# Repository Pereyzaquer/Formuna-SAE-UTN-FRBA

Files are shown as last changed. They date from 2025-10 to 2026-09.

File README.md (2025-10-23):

# Fórmula SAE - UTN-FRBA

<p>Este repositorio está destinado al equipo de <strong>Fórmula SAE UTN-FRBA</strong>.<br>
Su objetivo es centralizar y compartir los <strong>esquemáticos</strong>, <strong>código</strong> y <strong>documentación técnica</strong> correspondientes a las distintas áreas del proyecto.</p>

<p>Para consultas, dudas o reportes de problemas, comuníquese con el responsable del área correspondiente.</p>

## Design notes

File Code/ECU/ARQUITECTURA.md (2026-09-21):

# Arquitectura del firmware

Vista de alto nivel de como esta armado el codigo de la ECU y de los
nodos sensores.

- Como correr la prueba: [PRUEBA.txt](../PRUEBA.txt)
- Decisiones tomadas y pendientes: [TODO.txt](TODO.txt)
- Mapa de identificadores CAN: [include/can_ids.h](include/can_ids.h)

---

## 1. Que hay conectado

Cada sensor vive en su propia placa y publica por CAN. La ECU no lee
ningun sensor de forma directa: solo escucha el bus.

```mermaid
flowchart LR
    N1["Nodo temperatura<br/>NodeMCU + DHT11<br/>ID 0x480 - 1 Hz"]
    N2["Nodo rueda delantera<br/>Nano + LJ12A3 inductivo<br/>ID 0x200 - 20 Hz"]
    N3["Nodo rueda trasera<br/>ESP32-C3 + infrarrojo LM393<br/>ID 0x201 - 20 Hz"]
    BUS{{"Bus CAN 500 kbps"}}
    ECU["ECU<br/>ESP32-S3"]
    PC["Navegador<br/>celular o notebook"]

    N1 --> BUS
    N2 --> BUS
    N3 --> BUS
    BUS <--> ECU
    ECU -. "heartbeat 0x100 - 100 Hz" .-> BUS
    ECU ---|"WiFi propio<br/>192.168.4.1"| PC
```

Los dos sensores de rueda son distintos por dentro y comparten codigo:
los dos bajan su salida a cero cuando pasa algo por delante. Con dos
ruedas reportando, la ECU ya puede calcular la velocidad del auto y
descartar la que se aparta.

---

## 2. Como conectar todo

Armado de la prueba de banco: **una ECU y tres nodos, los cuatro por
modulo MCP2515.** Hay cuatro modulos HW-184, uno por placa.

### Lista de materiales

| Cantidad | Que | Para que |
| --- | --- | --- |
| 1 | ESP32-S3 (YD-ESP32-S3) | ECU |
| 1 | ESP32-C3 Super Mini | Nodo infrarrojo, rueda trasera |
| 1 | NodeMCU V3 LoLin (ESP8266) | Nodo DHT11 |
| 1 | Arduino Nano | Nodo inductivo, rueda delantera |
| 4 | Modulo HW-184 (MCP2515 + TJA1050) | Uno por placa |
| 2 | Conversor de nivel 5 V / 3.3 V, 4 canales | ECU y ESP32-C3 |
| 1 | Resistencia de 1 kohm | Divisor del NodeMCU, recomendado |
| 1 | Resistencia de 2 kohm (o 2.2) | Divisor del NodeMCU, recomendado |
| 1 | Modulo infrarrojo de obstaculos LM393 | Sensor de rueda trasera |
| 1 | DHT11 | Sensor de temperatura |
| 1 | LJ12A3-4-Z/BX | Sensor de rueda delantera |
| 2 | Algo que gire con una lengüeta | Uno de metal para el inductivo, uno de lo que sea para el infrarrojo |
| 4 | Cable USB | Alimentacion y programacion |

**Por que hay dos conversores y un divisor.** El HW-184 es de 5 V.
El Nano tambien: va directo. El ESP32-S3, el ESP32-C3 y el NodeMCU son
de 3.3 V y no toleran 5 V en sus entradas. Hay dos conversores: van a
los dos ESP32, con las cuatro lineas del SPI cada uno. Al NodeMCU no le
alcanza conversor, y se resuelve con dos resistencias en la unica linea
que vuelve del modulo con 5 V, la SO.

### Vista general

```mermaid
flowchart LR
    subgraph ecu["ECU - ESP32-S3"]
        S3["SPI GPIO 10-13"]
    end
    subgraph n1["Nodo rueda trasera - ESP32-C3"]
        C3["SPI GPIO 4-7<br/>GPIO 8 pulsos"]
    end
    subgraph n2["Nodo temperatura - NodeMCU"]
        NM["SPI D5 D6 D7, CS D2<br/>D1 datos"]
    end
    subgraph n3["Nodo rueda delantera - Nano"]
        NANO["SPI D10-D13<br/>D3 pulsos"]
    end

    SH1["Conversor<br/>de nivel"]
    SH2["Conversor<br/>de nivel"]
    DIV["Divisor 1k / 2k<br/>solo en SO"]
    M1["HW-184"]
    M2["HW-184"]
    M3["HW-184"]
    M4["HW-184"]
    BUS{{"CAN_H y CAN_L<br/>120 ohm solo en las dos puntas"}}

    S3 --- SH1 --- M1 --- BUS
    C3 --- SH2 --- M2 --- BUS
    NM --- DIV --- M3 --- BUS
    NANO --- M4 --- BUS

    IR["Infrarrojo LM393"] --- C3
    DHT["DHT11"] --- NM
    LJ["LJ12A3 inductivo"] --- NANO
```

Todas las masas van unidas: las cuatro placas, los cuatro modulos y
los conversores. Es lo primero que hay que cablear y lo primero que hay
que revisar si algo no anda.

### El bus CAN

| Conexion | Detalle |
| --- | --- |
| CAN_H | Un cable que pasa por la bornera H de los cuatro HW-184 |
| CAN_L | Idem con la L. Conviene trenzar los dos |
| Orden | Lineal: ECU - C3 - NodeMCU - Nano, o el que convenga, pero en fila, no en estrella |
| 120 ohm | **Solo en los dos modulos de las puntas.** Los dos del medio tienen que quedar sin terminador |
| Velocidad | 500 kbps, ya fijada en el codigo |

**Los terminadores.** Cada HW-184 trae su resistencia de 120 ohm con
un jumper marcado J1. Con cuatro modulos, dos son extremos y dos estan
en el medio: **quitar el jumper J1 en los dos del medio.** Si en vez de
jumper es un puente soldado, cortarlo. Con cuatro terminadores el bus
queda cargado de mas y aparecen errores intermitentes que enloquecen.

**El cristal del MCP2515.** Cada HW-184 tiene una lata metalica con un
numero: 8.000 o 16.000. El codigo asume **8 MHz** en las cuatro placas.
Si alguno dice 16, hay que cambiar `MCP2515_CRYSTAL` en el
`can_mcp2515.cpp` que corresponda. Si no coincide, ese nodo queda a otra
velocidad y no se entiende con nadie, sin ningun mensaje de error.

### Nodo rueda trasera: ESP32-C3 + conversor + HW-184 + infrarrojo

Alimentacion:

| De | A |
| --- | --- |
| C3 3.3V | Conversor lado LV, y VCC del modulo infrarrojo |
| C3 5V | Conversor lado HV, y VCC del HW-184 |
| C3 GND | Conversor GND, HW-184 GND, infrarrojo GND, masa comun |

SPI, las cuatro lineas por el conversor:

| ESP32-C3 | Conversor | HW-184 |
| --- | --- | --- |
| GPIO 4 | LV1 - HV1 | SCK |
| GPIO 6 | LV2 - HV2 | SI |
| GPIO 5 | LV3 - HV3 | SO |
| GPIO 7 | LV4 - HV4 | CS |
| — | — | INT: sin conectar |

Sensor infrarrojo LM393:

| Modulo | C3 |
| --- | --- |
| VCC | 3.3V |
| GND | GND |
| D0 | GPIO 8, directo. El modulo ya trae pull-up |

El modulo tiene un preset. Girarlo hasta que su led encienda con la
lengüeta delante y se apague sin ella, a la distancia a la que va a
trabajar. Si queda muy sensible dispara solo y las RPM salen infladas.

### Nodo temperatura: NodeMCU + divisor + HW-184 + DHT11

Alimentacion:

| De | A |
| --- | --- |
| NodeMCU VU (5 V del USB) | VCC del HW-184 |
| NodeMCU 3V3 | VCC del DHT11 |
| NodeMCU GND | HW-184 GND, DHT11 GND, masa comun |

SPI. Tres lineas van directo del NodeMCU al modulo con 3.3 V, que el
MCP2515 acepta. La que vuelve, SO, sale con 5 V y conviene bajarla con
el divisor. Sin el divisor anda: el ESP8266 aguanta 5 V en la practica,
aunque la hoja de datos no lo garantiza. Para el banco es aceptable
conectar SO directo a D6; para algo que dure, poner las dos
resistencias.

| NodeMCU | HW-184 |
| --- | --- |
| D5 | SCK, directo |
| D7 | SI, directo |
| D6 | SO, **por el divisor** |
| D2 | CS, directo |
| — | INT: sin conectar |

El divisor: 1 kohm entre SO del HW-184 y D6, y 2 kohm entre D6 y GND.
Los 5 V del modulo llegan a D6 como 3.3 V.

**No usar D8 como CS**: es un pin de arranque del ESP8266 y el modulo lo
puede dejar en un nivel que impide que la placa bootee. D2 no tiene ese
problema.

DHT11:

| DHT11 | NodeMCU |
| --- | --- |
| DATA | D1, directo. La libreria activa la pull-up interna del micro |
| VCC | 3V3 |
| GND | GND |

### Nodo rueda delantera: Nano + HW-184 + inductivo

Todo a 5 V, sin conversor ni divisor.

| Nano | HW-184 |
| --- | --- |
| D13 | SCK |
| D11 | SI |
| D12 | SO |
| D10 | CS |
| 5V | VCC |
| GND | GND |
| — | INT: sin conectar |

Sensor inductivo LJ12A3-4-Z/BX, alimentado con los 5 V del Nano:

| Cable | Nano |
| --- | --- |
| Marron | 5V |
| Azul | GND |
| Negro | D3, directo. El codigo activa la pull-up interna del Nano |

El sensor tiene un led que enciende al detectar metal. Sirve para
ajustar la distancia a la lengüeta, unos 2 a 3 mm, antes de conectar
nada. Alimentado con 5 V su salida no puede pasar de 5 V, asi que va
directo al Nano sin mas verificacion.

Si la lectura de RPM sale con ruido o saltos raros, agregar 4.7 kohm
entre D3 y 5V: es una pull-up mas fuerte que la interna del micro.

### ECU: ESP32-S3 + conversor + HW-184

Alimentacion:

| De | A |
| --- | --- |
| ESP32 3.3V | Conversor lado LV |
| ESP32 5V | Conversor lado HV, y VCC del HW-184 |
| ESP32 GND | Conversor GND, HW-184 GND, masa comun |

SPI, las cuatro lineas por el conversor:

| ESP32-S3 | Conversor | HW-184 |
| --- | --- | --- |
| GPIO 12 | LV1 - HV1 | SCK |
| GPIO 11 | LV2 - HV2 | SI |
| GPIO 13 | LV3 - HV3 | SO |
| GPIO 10 | LV4 - HV4 | CS |
| — | — | INT: sin conectar |

Opcional: GPIO 6 a un boton de arranque, el otro extremo a GND. La
pagina web tiene el suyo.

### Orden de armado

1. Masa comun entre todo.
2. Bus: CAN_H y CAN_L en fila por los cuatro HW-184. Quitar J1 en los
   dos del medio.
3. Cada placa con su HW-184, segun las tablas: conversor en los dos
   ESP32, divisor en el NodeMCU, directo en el Nano.
4. Los tres sensores.
5. Grabar. Desde `Code/ECU`: `pio run -t upload`. Desde
   `Code/SensorNode`: `pio run -e rueda_c3 -t upload`,
   `-e temperatura_nodemcu`, `-e rueda_nano`. Antes de cada una,
   `pio device list` para confirmar que placa esta enchufada.
6. Encender todo, entrar a `http://192.168.4.1/` y mirar "Nodos
   presentes" y "Bus caido". Tienen que ser 3 y un contador quieto.
   Si es asi, el bus esta bien y el resto es cuestion de sensores.

---

## 3. Maquina de estados del vehiculo

Un solo lugar del programa decide en que estado esta el auto:
[state.cpp](src/state.cpp).

```mermaid
stateDiagram-v2
    [*] --> BOOT

    BOOT --> CONFIG : nodos de seguridad OK, tras 2 s de escucha
    BOOT --> FAULT : falla de nodo de seguridad
    CONFIG --> CAR_READY : nodos presentes configurados
    CAR_READY --> CAR_ON : secuencia RTD completa
    CAR_ON --> CAR_READY : duracion cumplida, o apagado pedido

    CONFIG --> FAULT : error CRITICAL
    CAR_READY --> FAULT : error CRITICAL
    CAR_ON --> FAULT : error CRITICAL
    FAULT --> BOOT : la causa de la falla desaparecio

    note left of CAR_ON
        Perder nodos o ruedas es WARNING:
        no cambia el estado ni corta la grabacion.
    end note

    note right of FAULT
        Enclavado: se sale reiniciando el micro,
        o solo, si la causa desaparece: vuelve
        a BOOT y termina esperando el boton RTD.
    end note
```

El led RGB de debug muestra el estado: BOOT azul, CONFIG amarillo,
CAR_READY verde fijo, CAR_ON verde pulsante, FAULT rojo.

CONFIG dura unos 10 ms mientras no exista el mensaje de configuracion
de nodos, asi que en el led practicamente no se ve.

**Que pasa si un nodo se pierde.** Un corte de comunicacion no es una
falla del auto: no cambia el estado ni corta una grabacion en curso.
La ECU trabaja con los nodos que aparecieron en los 2 s de escucha, no
con la lista completa del auto: los que nunca estuvieron no cuentan.
Si uno de los que estaban deja de emitir mas de 3 s, queda un WARNING
(codigo 0x0002) en el monitor, y si se pierden todas las ruedas a la
vez el codigo es 0x0003 (se detecta en medio segundo, porque el piloto
se queda sin velocidad). Cuando todo vuelve, el aviso se borra solo y
la grabacion, si habia una, siguio como si nada. Lo definí así para el
banco; queda pendiente validar en el definitivo.

**Como se sale de FAULT.** FAULT queda para fallas de seguridad reales
(nodos de categoria B), que hoy no estan implementadas. Se sale
reiniciando el micro, o solo si la causa desaparece: la ECU se rearma
y vuelve a BOOT, con su ventana de descubrimiento, hasta quedar en
CAR_READY esperando el boton.

**Duracion de la ejecucion.** 90 s por defecto, definidos para el
banco. Se cambia desde la pagina antes de arrancar (campo "Duracion",
hasta 180 s); viaja con la orden de arranque.

**Contador de caidas.** Cada vez que un nodo se calla suma uno a su
contador. Los tres contadores se ven en el monitor y van al CSV como
canales (`caidas_rueda_delantera`, `caidas_rueda_trasera`,
`caidas_temperatura`): con el valor al arrancar la ejecucion y un
escalon por cada corte, para que en el grafico se vea cuando paso.

---

## 4. Como esta dividido el codigo de la ECU

Tres tasks. El nucleo 1 corre lo que tiene que ser predecible, y el 0
queda para la radio, que es donde el stack de WiFi ya corre lo suyo.

Las tasks no comparten variables sueltas: se hablan por colas.

```mermaid
flowchart LR
    subgraph nucleo1["Nucleo 1 - tiempo real"]
        direction TB
        taskCan["taskCan - prioridad 4<br/>can.cpp"]
        taskState["taskState - prioridad 3<br/>state.cpp"]
    end

    subgraph nucleo0["Nucleo 0 - radio"]
        taskWifi["taskWifi - prioridad 1<br/>wifi.cpp"]
    end

    taskState -- "queueWifi<br/>encender / apagar" --> taskWifi
    taskWifi -- "queueEvents<br/>arrancar / detener" --> taskState
```

Los demas archivos no tienen task propia: son modulos que las tasks
llaman.

| Archivo | Que hace | Quien lo usa |
| --- | --- | --- |
| `state.cpp` | Maquina de estados | taskState |
| `can.cpp` | Bus CAN: despacho, handlers y heartbeat | taskCan |
| `can_mcp2515.cpp` | Hardware del bus: modulo MCP2515 por SPI (banco) | can.cpp |
| `can_twai.cpp` | Hardware del bus: CAN interno del ESP32 (auto) | can.cpp |
| `wifi.cpp` | Punto de acceso y actualizacion OTA | taskWifi |
| `sensors.cpp` | Que nodos estan presentes | taskCan, taskState |
| `logger.cpp` | Guarda las muestras de la ejecucion | taskCan, webmonitor |
| `speed.cpp` | Velocidad del auto a partir de las ruedas | taskCan, taskState |
| `errors.cpp` | Registra y latchea las fallas | las tres tasks |
| `indicators.cpp` | Led RGB de debug | taskState |
| `webmonitor.cpp` | Pagina, JSON y CSV | taskWifi |

El bus CAN tiene mas prioridad que la maquina de estados a proposito:
no puede perder tramas esperando a que los estados terminen su vuelta.

---

## 5. Que pasa durante una ejecucion

```mermaid
sequenceDiagram
    participant Nodo as Nodo C3
    participant Can as taskCan
    participant Log as logger
    participant Est as taskState
    participant Web as webmonitor
    participant Nav as Navegador

    Note over Nodo,Can: El nodo emite solo, sin que nadie le pregunte

    Nodo->>Can: trama CAN
    Can->>Can: marca el nodo como presente
    Can->>Log: valor convertido a unidad real
    Note over Log: fuera de la ejecucion solo<br/>actualiza el valor en vivo

    Nav->>Web: POST /api/rtd
    Web->>Est: evento por queueEvents
    Est->>Log: loggerStart

    loop 90 segundos
        Nodo->>Can: trama CAN
        Can->>Log: se guarda la muestra
    end

    Est->>Log: la ejecucion termina sola
    Nav->>Web: GET /registro.csv
    Web->>Log: lee las muestras
    Web-->>Nav: CSV con una columna por canal
```

El nodo nunca espera una orden: arranca midiendo y emitiendo. Eso es lo
que permite que la ECU lo descubra con solo escuchar, y que un nodo
ausente no trabe nada.

---

## 6. Como se agrega un sensor nuevo

Del lado del nodo, un sensor son cuatro funciones declaradas en
[SensorNode.h](../SensorNode/include/SensorNode.h). `main.cpp` no sabe que
sensor tiene conectado: se lo pregunta a esa interfaz.

```mermaid
flowchart LR
    main["main.cpp<br/>no sabe que sensor hay"]
    api["Interfaz del sensor"]
    s1["sensor_temperature.cpp"]
    s2["sensor_wheel_speed.cpp"]
    s3["sensor_nuevo.cpp"]

    main --> api
    api --> s1
    api --> s2
    api -.-> s3

    s1 -.-> nota["sensorInitialize<br/>sensorGetCanIdentifier<br/>sensorGetPeriodMilliseconds<br/>sensorBuildFrame"]
```

Los pasos:

1. Copiar uno de los `sensor_*.cpp` e implementar las cuatro funciones.
2. Definir el identificador y el layout de su trama en `can_ids.h`:
   unidad, escala, rango y endianness. Si emisor y receptor no coinciden
   en los cuatro, el dato no falla, miente en silencio.
3. Agregar un entorno en el `platformio.ini` del nodo. El archivo del
   sensor se elige con `build_src_filter`, asi que no hace falta ningun
   `#ifdef`.
4. Del lado de la ECU, sumar el handler en `can.cpp` y el canal en
   `LogChannel`.

No hay que tocar `main.cpp` ni `can.cpp` del nodo.

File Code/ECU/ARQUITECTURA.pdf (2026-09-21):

# Arquitectura del firmware

Vista de alto nivel de como esta armado el codigo de la ECU y de los nodos sensores.

Como correr la prueba: PRUEBA.txt
Decisiones tomadas y pendientes: TODO.txt
Mapa de identificadores CAN: include/can_ids.h

## 1. Que hay conectado

Cada sensor vive en su propia placa y publica por CAN. La ECU no lee ningun sensor de forma directa: solo escucha el bus.

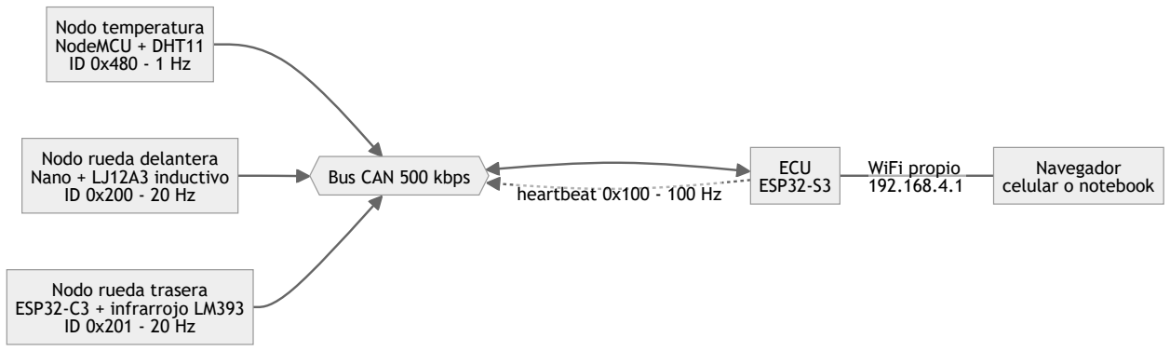
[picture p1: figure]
heartbeat 0x100 - 100 Hz; WiFi propio 192.168.4.1; Nodo temperatura NodeMCU + DHT11 ID 0x480 - 1 Hz; Nodo rueda delantera Nano + LJ12A3 inductivo ID 0x200 - 20 Hz; Nodo rueda trasera ESP32-C3 + infrarrojo LM393 ID 0x201 - 20 Hz; Bus CAN 500 kbps; ECU ESP32-S3; Navegador celular o notebook

Los dos sensores de rueda son distintos por dentro y comparten codigo: los dos bajan su salida a cero cuando pasa algo por delante. Con dos ruedas reportando, la ECU ya puede calcular la velocidad del auto y descartar la que se aparta.

## 2. Como conectar todo

Armado de la prueba de banco: una ECU y tres nodos, los cuatro por modulo MCP2515. Hay cuatro modulos HW-184, uno por placa.

Lista de materiales

Cantidad | Que | Para que
1 | ESP32-S3 (YD-ESP32-S3) | ECU
1 | ESP32-C3 Super Mini | Nodo infrarrojo, rueda trasera
1 | NodeMCU V3 LoLin (ESP8266) | Nodo DHT11
1 | Arduino Nano | Nodo inductivo, rueda delantera

Cantidad | Que | Para que
4 | Modulo HW-184 (MCP2515 + TJA1050) | Uno por placa
2 | Conversor de nivel 5 V / 3.3 V, 4 canales | ECU y ESP32-C3
1 | Resistencia de 1 kohm | Divisor del NodeMCU, recomendado
1 | Resistencia de 2 kohm (o 2.2) | Divisor del NodeMCU, recomendado
1 | Modulo infrarrojo de obstaculos LM393 | Sensor de rueda trasera
1 | DHT11 | Sensor de temperatura
1 | LJ12A3-4-Z/BX | Sensor de rueda delantera
2 | Algo que gire con una lengüeta | Uno de metal para el inductivo, uno de lo que sea para el infrarrojo
4 | Cable USB | Alimentacion y programacion

Por que hay dos conversores y un divisor. El HW-184 es de 5 V. El Nano tambien: va directo. El ESP32-S3, el ESP32-C3 y el NodeMCU son de 3.3 V y no toleran 5 V en sus entradas. Hay dos conversores: van a los dos ESP32, con las cuatro lineas del SPI cada uno. Al NodeMCU no le alcanza conversor, y se resuelve con dos resistencias en la unica linea que vuelve del modulo con 5 V, la SO.

Vista general

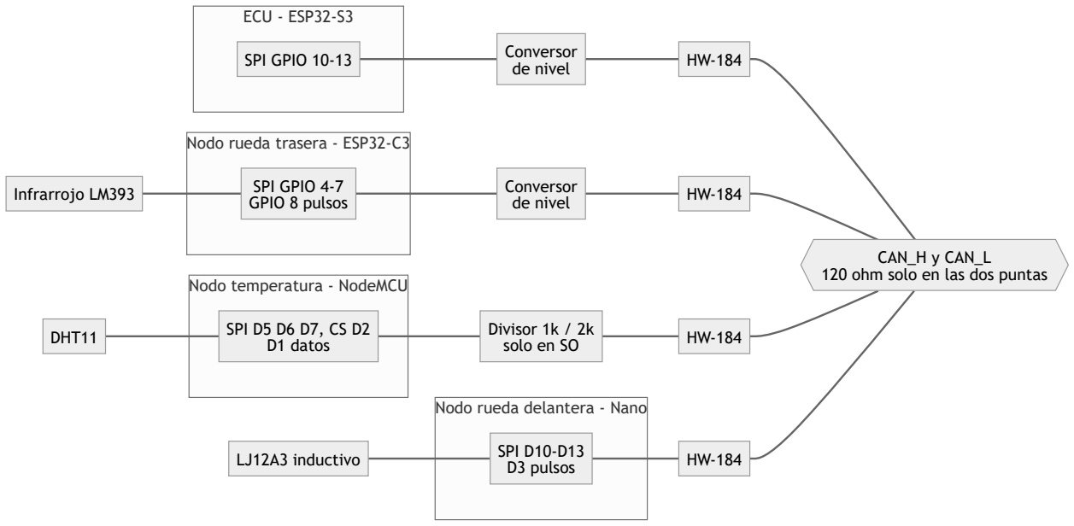
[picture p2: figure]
Nodo rueda delantera - Nano; Nodo temperatura - NodeMCU; Nodo rueda trasera - ESP32-C3; ECU - ESP32-S3; SPI D10-D13 D3 pulsos; SPI D5 D6 D7, CS D2 D1 datos; SPI GPIO 4-7 GPIO 8 pulsos; SPI GPIO 10-13; Conversor de nivel; Divisor 1k / 2k solo en SO; CAN_H y CAN_L 120 ohm solo en las dos puntas; Infrarrojo LM393; DHT11; LJ12A3 inductivo

Todas las masas van unidas: las cuatro placas, los cuatro modulos y los conversores. Es lo primero que hay que cablear y lo primero que hay que revisar si algo no anda.

El bus CAN

Conexion | Detalle
CAN_H | Un cable que pasa por la bornera H de los cuatro HW-184
CAN_L | Idem con la L. Conviene trenzar los dos
Orden | Lineal: ECU - C3 - NodeMCU - Nano, o el que convenga, pero en fila, no en estrella
120 ohm | Solo en los dos modulos de las puntas. Los dos del medio tienen que quedar sin terminador
Velocidad | 500 kbps, ya fijada en el codigo

Los terminadores. Cada HW-184 trae su resistencia de 120 ohm con un jumper marcado J1. Con cuatro modulos, dos son extremos y dos estan en el medio: quitar el jumper J1 en los dos del medio. Si en vez de jumper es un puente soldado, cortarlo. Con cuatro terminadores el bus queda cargado de mas y aparecen errores intermitentes que enloquecen.

El cristal del MCP2515. Cada HW-184 tiene una lata metalica con un numero: 8.000 o 16.000. El codigo asume 8 MHz en las cuatro placas. Si alguno dice 16, hay que cambiar MCP2515_CRYSTAL en el can_mcp2515.cpp que corresponda. Si no coincide, ese nodo queda a otra velocidad y no se entiende con nadie, sin ningun mensaje de error.

Nodo rueda trasera: ESP32-C3 + conversor + HW-184 + infrarrojo

Alimentacion:

De | A
C3 3.3V | Conversor lado LV, y VCC del modulo infrarrojo
C3 5V | Conversor lado HV, y VCC del HW-184
C3 GND | Conversor GND, HW-184 GND, infrarrojo GND, masa comun

SPI, las cuatro lineas por el conversor:

ESP32-C3 | Conversor | HW-184
GPIO 4 | LV1 - HV1 | SCK
GPIO 6 | LV2 - HV2 | SI
GPIO 5 | LV3 - HV3 | SO
GPIO 7 | LV4 - HV4 | CS
— | — | INT: sin conectar

Sensor infrarrojo LM393:

Modulo | C3
VCC | 3.3V
GND | GND
D0 | GPIO 8, directo. El modulo ya trae pull-up

El modulo tiene un preset. Girarlo hasta que su led encienda con la lengüeta delante y se apague sin ella, a la distancia a la que va a trabajar. Si queda muy sensible dispara solo y las RPM salen infladas.

Nodo temperatura: NodeMCU + divisor + HW-184 + DHT11

Alimentacion:

De | A
NodeMCU VU (5 V del USB) | VCC del HW-184
NodeMCU 3V3 | VCC del DHT11
NodeMCU GND | HW-184 GND, DHT11 GND, masa comun

SPI. Tres lineas van directo del NodeMCU al modulo con 3.3 V, que el MCP2515 acepta. La que vuelve, SO, sale con 5 V y conviene bajarla con el divisor. Sin el divisor anda: el ESP8266 aguanta 5 V en la practica, aunque la hoja de datos no lo garantiza. Para el banco es aceptable conectar SO directo a D6; para algo que dure, poner las dos resistencias.

NodeMCU | HW-184
D5 | SCK, directo
D7 | SI, directo
D6 | SO, por el divisor
D2 | CS, directo
— | INT: sin conectar

El divisor: 1 kohm entre SO del HW-184 y D6, y 2 kohm entre D6 y GND. Los 5 V del modulo llegan a D6 como 3.3 V.

No usar D8 como CS: es un pin de arranque del ESP8266 y el modulo lo puede dejar en un nivel que impide que la placa bootee. D2 no tiene ese problema.

DHT11:

DHT11 | NodeMCU
DATA | D1, directo. La libreria activa la pull-up interna del micro
VCC | 3V3

DHT11 | NodeMCU
GND | GND

Nodo rueda delantera: Nano + HW-184 + inductivo

Todo a 5 V, sin conversor ni divisor.

Nano | HW-184
D13 | SCK
D11 | SI
D12 | SO
D10 | CS
5V | VCC
GND | GND
— | INT: sin conectar

Sensor inductivo LJ12A3-4-Z/BX, alimentado con los 5 V del Nano:

Cable | Nano
Marron | 5V
Azul | GND
Negro | D3, directo. El codigo activa la pull-up interna del Nano

El sensor tiene un led que enciende al detectar metal. Sirve para ajustar la distancia a la lengüeta, unos 2 a 3 mm, antes de conectar nada. Alimentado con 5 V su salida no puede pasar de 5 V, asi que va directo al Nano sin mas verificacion.

Si la lectura de RPM sale con ruido o saltos raros, agregar 4.7 kohm entre D3 y 5V: es una pull-up mas fuerte que la interna del micro.

ECU: ESP32-S3 + conversor + HW-184

Alimentacion:

De | A
ESP32 3.3V | Conversor lado LV
ESP32 5V | Conversor lado HV, y VCC del HW-184
ESP32 GND | Conversor GND, HW-184 GND, masa comun

SPI, las cuatro lineas por el conversor:

ESP32-S3 | Conversor | HW-184
GPIO 12 | LV1 - HV1 | SCK
GPIO 11 | LV2 - HV2 | SI
GPIO 13 | LV3 - HV3 | SO
GPIO 10 | LV4 - HV4 | CS
— | — | INT: sin conectar

Opcional: GPIO 6 a un boton de arranque, el otro extremo a GND. La pagina web tiene el suyo.

Orden de armado

1. Masa comun entre todo.
2. Bus: CAN_H y CAN_L en fila por los cuatro HW-184. Quitar J1 en los dos del medio.
3. Cada placa con su HW-184, segun las tablas: conversor en los dos ESP32, divisor en el NodeMCU, directo en el Nano.
4. Los tres sensores.
5. Grabar. Desde Code/ECU : pio run -t upload . Desde Code/SensorNode : pio run -e rueda_c3 -t upload , -e temperatura_nodemcu , -e rueda_nano . Antes de cada una, pio device list para
confirmar que placa esta enchufada.
6. Encender todo, entrar a http://192.168.4.1/ y mirar "Nodos presentes" y "Bus caido". Tienen que ser 3 y un contador quieto. Si es asi, el bus esta bien y el resto es cuestion de sensores.

## 3. Maquina de estados del vehiculo

Un solo lugar del programa decide en que estado esta el auto: state.cpp.

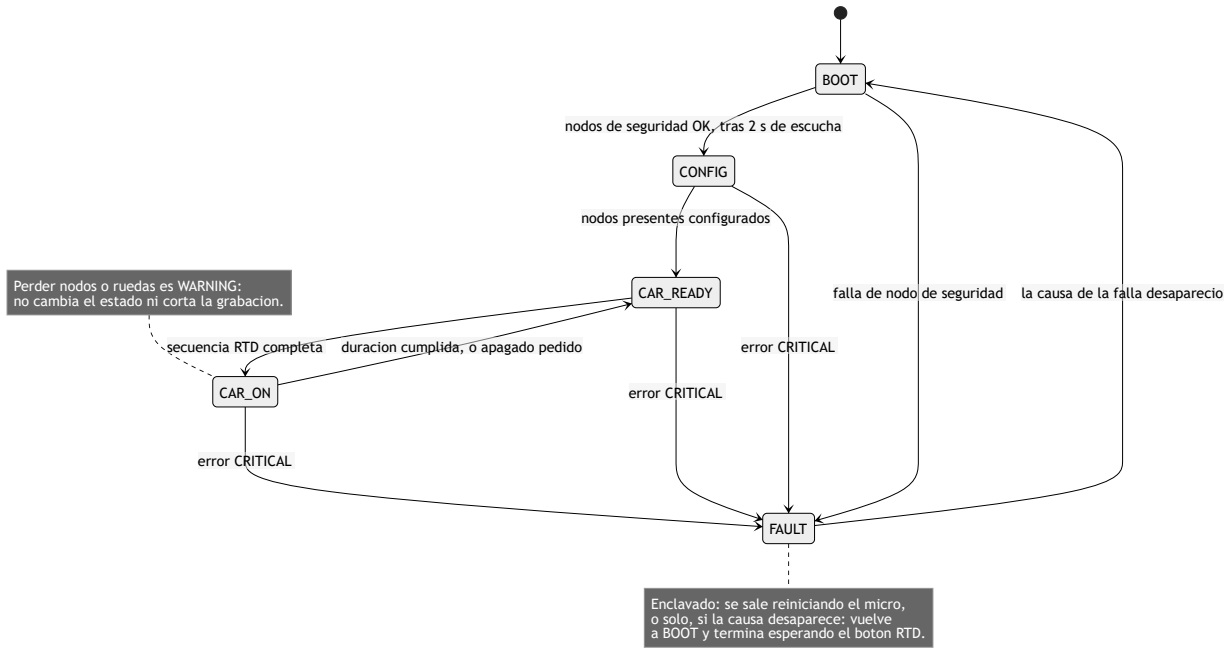
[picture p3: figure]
falla de nodo de seguridad; nodos presentes configurados; secuencia RTD completa; duracion cumplida, o apagado pedido; error CRITICAL; la causa de la falla desaparecio; BOOT; CONFIG; FAULT; CAR_READY; CAR_ON; Perder nodos o ruedas es WARNING:; o solo, si la causa desaparece: vuelve

nodos de seguridad OK, tras 2 s de escucha

no cambia el estado ni corta la grabacion.

Enclavado: se sale reiniciando el micro,

a BOOT y termina esperando el boton RTD.

El led RGB de debug muestra el estado: BOOT azul, CONFIG amarillo, CAR_READY verde fijo, CAR_ON verde pulsante, FAULT rojo.

CONFIG dura unos 10 ms mientras no exista el mensaje de configuracion de nodos, asi que en el led practicamente no se ve.

Que pasa si un nodo se pierde. Un corte de comunicacion no es una falla del auto: no cambia el estado ni corta una grabacion en curso. La ECU trabaja con los nodos que aparecieron en los 2 s de escucha, no con la lista completa del auto: los que nunca estuvieron no cuentan. Si uno de los que estaban deja de emitir mas de 3 s, queda un WARNING (codigo 0x0002) en el monitor, y si se pierden todas las ruedas a la vez el codigo es 0x0003 (se detecta en medio segundo, porque el piloto se queda sin velocidad). Cuando todo vuelve, el aviso se borra solo y la grabacion, si habia una, siguio como si nada. Lo definí así para el banco; queda pendiente validar en el definitivo.

Como se sale de FAULT. FAULT queda para fallas de seguridad reales (nodos de categoria B), que hoy no estan implementadas. Se sale reiniciando el micro, o solo si la causa desaparece: la ECU se rearma y vuelve a BOOT, con su ventana de descubrimiento, hasta quedar en CAR_READY esperando el boton.

Duracion de la ejecucion. 90 s por defecto, definidos para el banco. Se cambia desde la pagina antes de arrancar (campo "Duracion", hasta 180 s); viaja con la orden de arranque.

Contador de caidas. Cada vez que un nodo se calla suma uno a su contador. Los tres contadores se ven en
el monitor y van al CSV como canales ( caidas_rueda_delantera , caidas_rueda_trasera ,
caidas_temperatura ): con el valor al arrancar la ejecucion y un escalon por cada corte, para que en el grafico se vea cuando paso.

## 4. Como esta dividido el codigo de la ECU

Tres tasks. El nucleo 1 corre lo que tiene que ser predecible, y el 0 queda para la radio, que es donde el stack de WiFi ya corre lo suyo.

Las tasks no comparten variables sueltas: se hablan por colas.

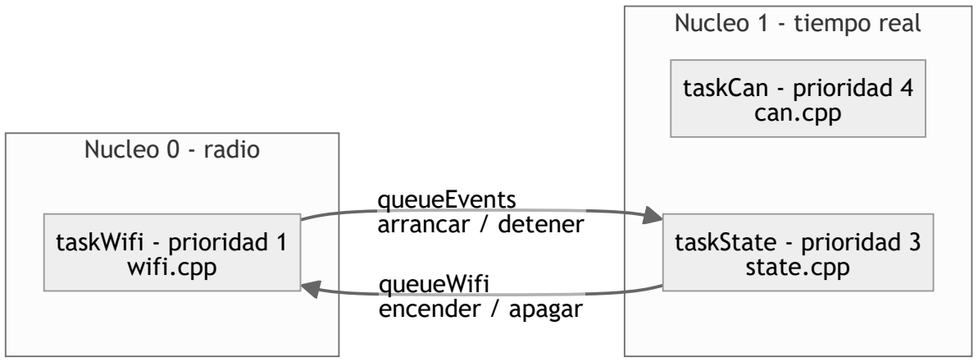
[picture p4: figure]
Nucleo 0 - radio; Nucleo 1 - tiempo real; queueWifi encender / apagar; queueEvents; wifi.cpp; taskCan - prioridad 4 can.cpp; taskState - prioridad 3 state.cpp

arrancar / detener taskWifi - prioridad 1

Los demas archivos no tienen task propia: son modulos que las tasks llaman.

Archivo | Que hace | Quien lo usa
state.cpp | Maquina de estados | taskState
can.cpp | Bus CAN: despacho, handlers y heartbeat | taskCan
can_mcp2515.cpp | Hardware del bus: modulo MCP2515 por SPI (banco) | can.cpp
can_twai.cpp | Hardware del bus: CAN interno del ESP32 (auto) | can.cpp
wifi.cpp | Punto de acceso y actualizacion OTA | taskWifi
sensors.cpp | Que nodos estan presentes | taskCan, taskState
logger.cpp | Guarda las muestras de la ejecucion | taskCan, webmonitor
speed.cpp | Velocidad del auto a partir de las ruedas | taskCan, taskState
errors.cpp | Registra y latchea las fallas | las tres tasks
indicators.cpp | Led RGB de debug | taskState
webmonitor.cpp | Pagina, JSON y CSV | taskWifi

El bus CAN tiene mas prioridad que la maquina de estados a proposito: no puede perder tramas esperando a que los estados terminen su vuelta.

## 5. Que pasa durante una ejecucion

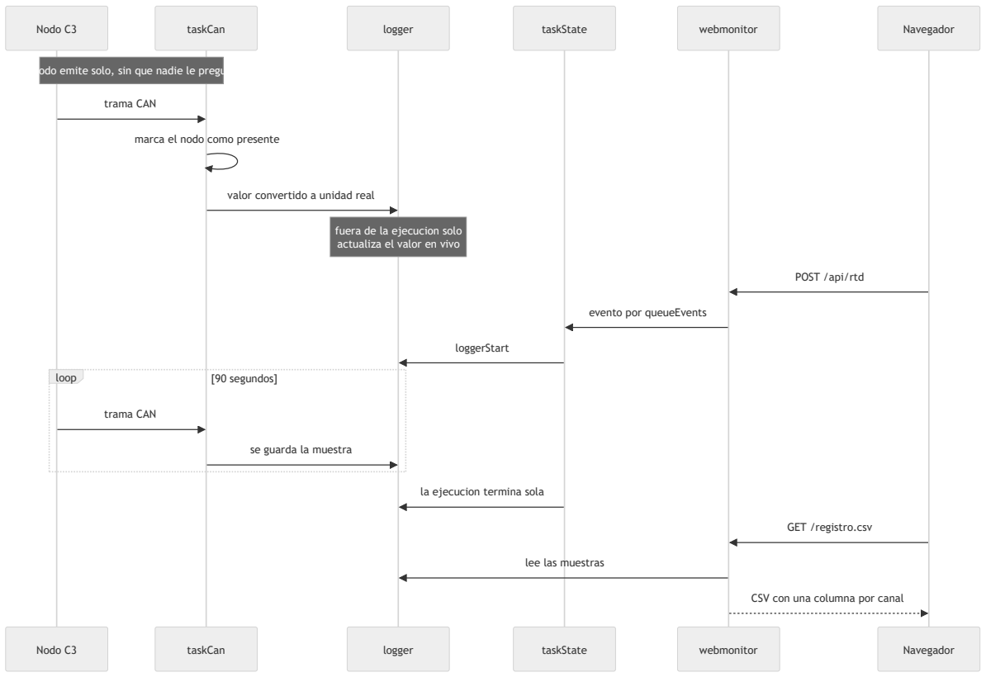
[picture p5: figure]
Nodo C3; taskCan; logger; taskState; webmonitor; Navegador; fuera de la ejecucion solo actualiza el valor en vivo; loop; [90 segundos]; trama CAN; marca el nodo como presente; valor convertido a unidad real; POST /api/rtd; evento por queueEvents; loggerStart; se guarda la muestra; la ejecucion termina sola; GET /registro.csv; lee las muestras; CSV con una columna por canal

El nodo emite solo, sin que nadie le pregunte

El nodo nunca espera una orden: arranca midiendo y emitiendo. Eso es lo que permite que la ECU lo descubra con solo escuchar, y que un nodo ausente no trabe nada.

## 6. Como se agrega un sensor nuevo

Del lado del nodo, un sensor son cuatro funciones declaradas en SensorNode.h. main.cpp no sabe que sensor tiene conectado: se lo pregunta a esa interfaz.

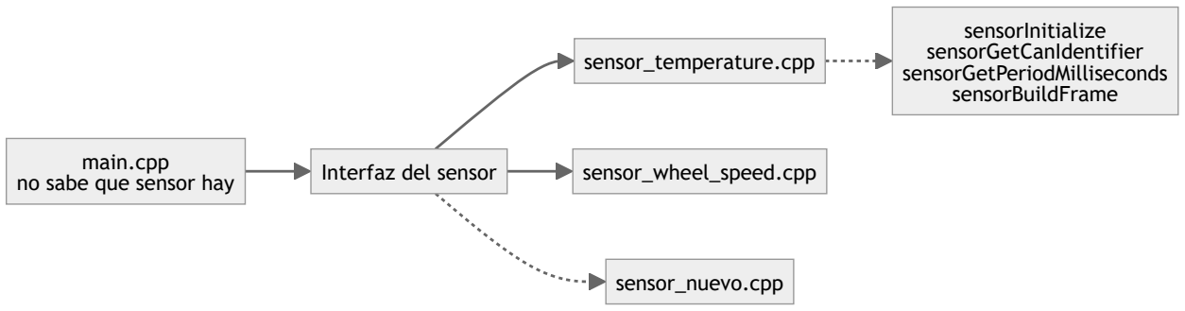
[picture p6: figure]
main.cpp no sabe que sensor hay; Interfaz del sensor; sensor_temperature.cpp; sensor_wheel_speed.cpp; sensor_nuevo.cpp; sensorInitialize sensorGetCanIdentifier sensorGetPeriodMilliseconds sensorBuildFrame

Los pasos:

1. Copiar uno de los sensor_*.cpp e implementar las cuatro funciones.

2. Definir el identificador y el layout de su trama en can_ids.h : unidad, escala, rango y endianness. Si emisor y receptor no coinciden en los cuatro, el dato no falla, miente en silencio.
3. Agregar un entorno en el platformio.ini del nodo. El archivo del sensor se elige con build_src_filter , asi que no hace falta ningun #ifdef .
4. Del lado de la ECU, sumar el handler en can.cpp y el canal en LogChannel .

No hay que tocar main.cpp ni can.cpp del nodo.

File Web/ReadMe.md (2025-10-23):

# Información del Proyecto

Este repositorio contiene el código de mantenimiento de la página web del equipo.
Inicialmente, el desarrollo está a cargo de Martín Ibazete.

Para cualquier duda, consulta o modificación relacionada con el sitio, por favor comunicarse con Martín Ibazete o con el responsable del área correspondiente.

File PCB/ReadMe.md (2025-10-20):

# Organización del repositorio

Para mantener un orden y facilitar el trabajo colaborativo, se recomienda seguir las siguientes pautas:

1. **Crear una carpeta por proyecto**, con un nombre descriptivo, para mantener separados los distintos desarrollos.

2. Colocar un ReadMe.md con la organizacion de la carpeta y los integrantes involucrados
3. **Coordinar con el resto del equipo** antes de realizar cambios importantes, para asegurar una correcta integración y evitar conflictos.
4. **Centralizar los símbolos y huellas** en dos carpetas específicas:
   - `Formula_SAE_FP`: destinada a guardar todos los **footprints (huellas)** creados o agregados.  
   - `Formula_SAE_SIM`: destinada a guardar todos los **símbolos esquemáticos** creados o agregados.

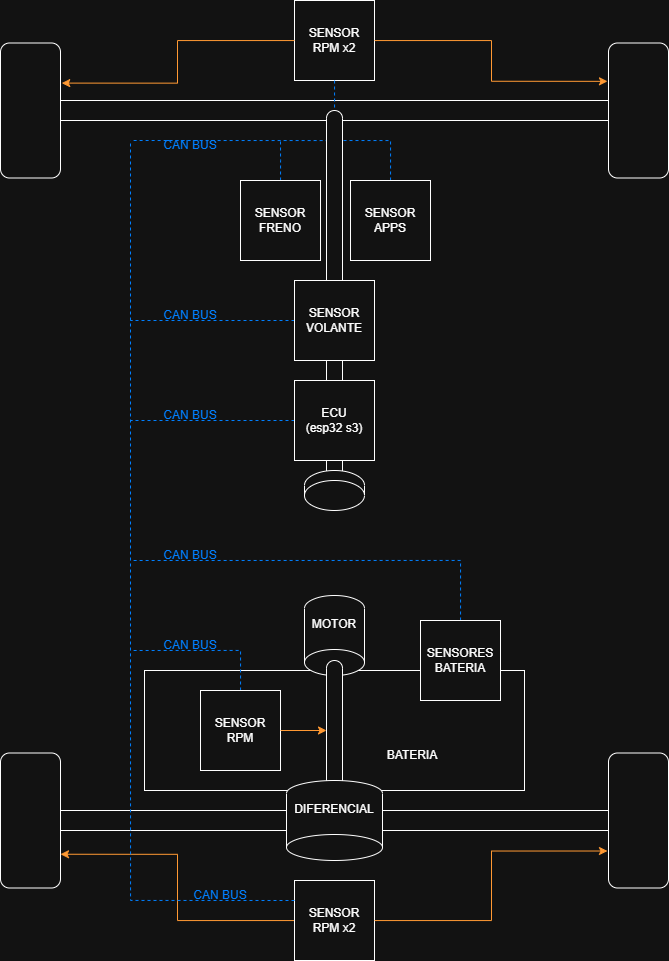
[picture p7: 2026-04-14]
Img/Diagrama de sensores/Diagrama de sensores del auto.png

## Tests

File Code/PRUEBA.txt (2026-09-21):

============================================================
 Proyecto : ECU + SensorNode
 Archivo  : PRUEBA.txt
 Equipo   : UTN BA Motorsport Formula student team
 Fecha    : 2/9/2026

 Descripcion:
 ------------------------------------------------------------
 Como correr la prueba de banco: una ECU ESP32-S3 y tres
 nodos sensores comunicados por CAN, grabando 90 segundos de
 datos que despues se bajan por wifi como archivo CSV.
============================================================

------------------------------------------------------------
 QUE HACE LA PRUEBA
------------------------------------------------------------
1. La ECU arranca y escucha el bus 2 segundos para ver que
   nodos hay. No le pregunta nada a nadie: los nodos emiten
   solos y por eso alcanza con escuchar.
2. Pasa por CONFIG y queda en CAR_READY, led verde fijo,
   esperando la orden de arranque.
3. Al apretar "Ready to move" en la pagina web, o el boton
   fisico si hay uno, entra en CAR_ON, led verde pulsante, y
   empieza a grabar.
4. A los 90 segundos la grabacion termina sola y la ECU vuelve
   a CAR_READY.
5. Se baja el CSV desde el navegador y se grafica.

Funciona con los tres nodos, con algunos, o con ninguno. Un
nodo ausente no traba nada: su columna en el CSV queda vacia y
el resto de la prueba sigue igual.

------------------------------------------------------------
 CABLEADO
------------------------------------------------------------
El detalle completo, con tablas pin por pin y el orden de
armado, esta en ECU/ARQUITECTURA.md, seccion "Como conectar
todo". Leerla entera antes de armar. Esto es el resumen.

Cuatro placas, cada una con su modulo HW-184 (MCP2515):

  ECU       ESP32-S3    SPI por conversor de nivel
  Trasera   ESP32-C3    SPI por conversor de nivel, infrarrojo
  Temp      NodeMCU     SPI, divisor 1k/2k en SO recomendado, DHT11
  Delantera Nano        SPI directo, inductivo a 5 V

Bus CAN: CAN_H y CAN_L en fila por los cuatro modulos. Quitar
el jumper J1 (terminador de 120 ohm) en los DOS DEL MEDIO;
queda solo en las dos puntas.

MASA COMUN entre todo. Sin eso nada anda.

Cristal del MCP2515: el codigo asume 8 MHz en las cuatro
placas. Mirar la lata de cada modulo; si alguno dice 16.000,
cambiar MCP2515_CRYSTAL en el can_mcp2515.cpp de esa placa.

Los numeros de pin estan definidos en ECU.h y en SensorNode.h.
Si el cableado real termina siendo otro, se cambian ahi y en
ningun otro lado.

------------------------------------------------------------
 GRABAR LAS PLACAS
------------------------------------------------------------
Antes de grabar, siempre:
    pio device list

Sirve para confirmar que la placa que se quiere grabar esta
enchufada. Si no lo esta, PlatformIO agarra cualquier otro
puerto serie de la maquina e intenta grabarle el firmware.

ECU, desde Code/ECU:
    pio run -t upload

Los tres nodos, desde Code/SensorNode:
    pio run -e rueda_c3 -t upload             ESP32-C3, infrarrojo
    pio run -e temperatura_nodemcu -t upload  NodeMCU, DHT11
    pio run -e rueda_nano -t upload           Nano, inductivo

Si la grabacion del Nano falla con "not in sync", tiene el
bootloader viejo: en platformio.ini cambiar nanoatmega328new
por nanoatmega328.

Los entornos del nodo comparten todo el codigo salvo el archivo
del sensor. No hay que cambiar nada a mano entre una grabacion
y la otra.

------------------------------------------------------------
 CORRER LA PRUEBA
------------------------------------------------------------
1. Alimentar todas las placas y esperar unos segundos.

2. Conectarse a la red wifi que levanta la ECU:
       Red:          ESP32 S3 ECU
       Contraseña:   12345678

3. Abrir en el navegador:
       http://192.168.4.1/

   Ahi se ve el estado, cuantos nodos se detectaron, y el valor
   en vivo de cada canal. ANTES de apretar el boton conviene
   mirar que el sensor este dando numeros razonables: es la
   forma de descubrir un cable flojo sin gastar una ejecucion.

4. Apretar "Ready to move" en la pagina, o el boton fisico
   si hay uno conectado. El led pasa a verde pulsante y la
   barra de avance empieza a moverse.

   El boton se habilita solo en CAR_READY. Si aparece gris, la
   ECU todavia no llego a ese estado.

5. Esperar 90 segundos. La grabacion termina sola. Si algo
   salio mal y no vale la pena esperar, "Detener" corta la
   ejecucion y conserva lo grabado hasta ese momento.

6. Bajar el archivo desde el enlace de la pagina, o directo:
       http://192.168.4.1/registro.csv

------------------------------------------------------------
 EL ARCHIVO CSV
------------------------------------------------------------
Sale con una columna por canal, tenga datos o no:

  tiempo_s, temperatura_C, humedad_pct, rpm_delantera_izq,
  rpm_delantera_der, rpm_trasera_izq, rpm_trasera_der,
  velocidad_kmh, acelerador_pct, freno_bar,
  caidas_rueda_delantera, caidas_rueda_trasera, caidas_temperatura

Las tres columnas caidas_* cuentan cuantas veces se callo cada
nodo desde que se encendio la ECU. Traen el valor al arrancar la
ejecucion y una fila nueva en cada corte, asi en el grafico se
ve un escalon justo cuando paso.

Cada fila es una muestra y solo lleva valor en la columna del
canal que hablo en ese instante. Las demas quedan vacias.

Eso es a proposito: una celda vacia es un hueco en el grafico,
que es lo correcto. Si se rellenara con cero, el grafico
mostraria una medicion que nunca existio.

Con los tres nodos de la prueba se llenan temperatura_C,
humedad_pct, rpm_delantera_izq, rpm_trasera_izq y
velocidad_kmh. Quedan vacias las dos ruedas derechas,
acelerador_pct y freno_bar, porque no hay ningun nodo que las
alimente. Estan igual para comprobar que la ECU maneja bien el
caso de varios canales definidos con solo algunos con datos.

velocidad_kmh la calcula la ECU, no la mide nadie: promedia las
ruedas que estan reportando y descarta la que se aparta mas de
5 km/h de las demas. Con las dos ruedas de la prueba, si giran
parecido se promedian; si una va mucho mas rapido que la otra,
las dos quedan fuera y la velocidad se marca como no confiable.
Es la forma de probar esa regla.

Para graficar: el CSV se abre en Excel, en Python o en MoTeC
i2. 
Para motec: https://app.notion.com/p/fsae-utn-frba-electronica/Motec-i2-Conversor-de-CSV-a-LD-2eed1b4deb1480cdb61ff08b69d709eb

------------------------------------------------------------
 PRUEBA COMPLETA, PASO A PASO
------------------------------------------------------------
Lo que tiene que pasar en cada paso. Si algo no coincide, ir a
"SI ALGO NO ANDA". Todo se mira en http://192.168.4.1 y, si la
ECU esta en la PC, en su puerto serie a 115200.

 1. Arranque de la ECU sola (nodos apagados).
    Led azul 2 s, luego verde. Serie: BOOT -> CONFIG -> CAR_READY.
    Pagina: 0 nodos, 0 tramas, falla NONE. "Bus caido" puede subir
    mientras esta sola; se queda quieto al enchufar un nodo.

 2. Enchufar los nodos de a uno.
    Con cada uno, "Tramas CAN" sube mas rapido y "Nodos presentes"
    suma 1. Nano: rpm_delantera_izq pasa de "sin datos" a 0.0.
    C3: rpm_trasera_izq a 0.0 y "Ruedas midiendo" 2 de 4.
    NodeMCU: temperatura_C y humedad_pct con valores razonables
    (ambiente). Si un nodo se enchufa despues de los 2 s de
    arranque igual aparece: la deteccion es continua.

 3. Sensores, uno por uno.
    - Inductivo (Nano): acercar un tornillo o una llave a la cara
      del sensor a menos de 4 mm, varias veces seguidas. El led del
      sensor parpadea con cada pasada y rpm_delantera_izq sube
      mientras se lo mueve (a mano, del orden de 60 a 200 RPM) y
      vuelve a 0.0 al segundo de parar.
    - Infrarrojo (C3): pasar la mano o un carton a unos 5 cm del
      modulo, repetidas veces. El led del modulo parpadea y
      rpm_trasera_izq sube. Si sube solo sin nada enfrente, bajar
      la sensibilidad con el preset del modulo.
    - DHT11 (NodeMCU): soplar o apoyar el dedo en el sensor:
      temperatura_C sube un par de grados en 10 a 20 s y humedad_pct
      salta. Es lento por diseno, una lectura por segundo.

 4. Velocidad calculada.
    Mover las dos ruedas a ritmo parecido: velocidad_kmh toma el
    promedio. Mover una sola: velocidad_kmh sigue esa rueda. Mover
    una rapido y la otra lenta (mas de 5 km/h de diferencia entre
    ellas): la velocidad queda "sin datos", porque ninguna es
    confiable. Es la regla de descarte funcionando.

 5. Caida de un nodo (WARNING).
    Desenchufar el USB del Nano (no el NodeMCU: presta los 5 V al
    modulo de la ECU). A los 3 s: serie "nodo 0x200 dejo de emitir
    (caida 1)", pagina WARNING (0x0002), ruedas 1 de 4,
    caidas_rueda_delantera = 1. Enchufar: "comunicacion
    restablecida", falla NONE, ruedas 2 de 4. El estado no cambio.

 6. Perdida de todas las ruedas (WARNING 0x0003).
    Desenchufar Nano y C3 a la vez. En medio segundo la pagina pasa
    a WARNING (0x0003), ruedas 0 de 4. El estado NO cambia: si habia
    una ejecucion en curso, sigue grabando. Enchufar cualquiera de
    los dos: falla NONE (o 0x0002 si el otro sigue afuera).

 7. Ejecucion y CSV.
    Poner la duracion en el campo "Duracion" (90 s por defecto,
    hasta 180) y "Ready to move" (o el boton fisico, pin 6 a
    GND). Led verde pulsante, CAR_READY -> CAR_ON, "Muestras"
    subiendo. Durante la ejecucion hacer los pasos 3, 5 y 6: la
    grabacion tiene que seguir y terminar sola a su tiempo, con
    CAR_ON -> CAR_READY. Bajar registro.csv y graficar: temperatura
    y humedad casi planas, rpm con picos donde se movieron las
    ruedas, velocidad con la misma forma, y las columnas caidas_*
    con un escalon en el instante de cada desconexion. Si se corto
    antes con "Detener", el CSV llega hasta ahi.

    Apagar la ECU en medio de una ejecucion la pierde: las muestras
    viven en RAM. Es una limitacion conocida hasta que haya SD.

 8. Wifi y OTA (opcional).
    Con la ECU en CAR_ON la red sigue visible. Desde Code/ECU:
      pio run -e ota -t upload
    graba por wifi; la ECU reinicia y vuelve sola a CAR_READY.

------------------------------------------------------------
 SI ALGO NO ANDA
------------------------------------------------------------
El led queda en rojo apenas arranca
    No se pudo inicializar el bus CAN: el ESP32 no consigue
    hablarle al MCP2515 por SPI. No es el bus H/L ni los otros
    nodos, es el tramo ESP32 -> conversor -> HW-184. Lo que
    fallo en el primer armado, en este orden:
      - El pin 5V del YD-ESP32-S3 NO entrega tension de fabrica:
        hay un puente de soldadura marcado IN-OUT al lado del
        pin que viene abierto. Sin 5 V el modulo se "prende"
        tenue por la linea CS y no responde. Soldar el puente,
        o tomar los 5 V de otra placa (VU del NodeMCU) con las
        masas unidas.
      - Contactos del protoboard: el conversor de nivel y sus
        cables no hacian contacto. Solucion que anduvo: sacar
        el conversor del protoboard y poner los cables Dupont
        directo a sus patas.
      - Orden de patas del conversor: LV1 LV2 LV GND LV3 LV4
        (y lo mismo en HV). LV3 y LV4 NO estan al lado de LV2.
      - HV1/HV2 cruzados.
    El modulo con luz roja solo dice que tiene 5 V, no que
    responda.

La pagina dice 0 nodos presentes y 0 tramas
    La ECU no recibe nada. Revisar masa comun entre placas, las
    dos resistencias de 120 ohm, y que CAN_H y CAN_L no esten
    cruzados. Tambien que los dos extremos esten a 500 kbps: si
    un nodo usa otra velocidad, ensucia el bus para todos.
    En el primer armado fue un cable H/L flojo del lado de la
    ECU: iba y venia al tocarlo. Los tornillos de la bornera
    tienen que morder el cobre, no la funda.

No se puede grabar el Nano ("not in sync")
    Los Nano del equipo tienen el bootloader viejo. El entorno
    rueda_nano ya usa board nanoatmega328; si un Nano nuevo
    falla igual, cambiar a nanoatmega328new.

El ESP32-C3 no muestra nada en el monitor serie
    El Super Mini solo tiene el USB nativo. El entorno rueda_c3
    ya lleva ARDUINO_USB_CDC_ON_BOOT=1 para que Serial salga por
    ahi; sin eso el texto se va a los pines del UART.

El monitor serie del ESP32-S3 se queda mudo al apretar RESET
    Con el USB nativo, al reiniciar el puerto desaparece un
    instante y el monitor de PlatformIO a veces no se
    reengancha. Cerrarlo (Ctrl+C) y abrirlo de nuevo.

Un nodo desaparece y la pagina dice WARNING (0x0002)
    Es lo esperado: un nodo que estaba y lleva mas de 3 s sin
    emitir se da por caido. Suma uno a su contador de caidas y
    queda el aviso hasta que vuelva. La ECU no se detiene.
    Los nodos que nunca estuvieron no cuentan: la ECU trabaja
    con los que aparecieron en los 2 s de arranque.

Se desconectan los DOS nodos de rueda y aparece WARNING (0x0003)
    Es lo esperado: perder todas las ruedas a la vez tiene su
    codigo propio porque el piloto se queda sin velocidad, y se
    detecta en medio segundo. No es falla del auto: el estado no
    cambia y la grabacion sigue. Cuando vuelve alguna rueda el
    aviso se borra.

La ECU esta en FAULT (cartel rojo, "FALLA - ECU" en la pestaña)
    Solo pasa por una falla de seguridad (categoria B), que hoy
    no existe en el banco. Se sale reiniciando la ECU, o sola si
    la causa desaparece: vuelve a BOOT y termina en CAR_READY
    esperando el boton.

El contador "Bus caido" sube sin parar
    Es normal si la ECU esta encendida sola: en CAN toda trama
    tiene que ser confirmada por otro nodo, y sin nadie que la
    confirme el controlador se desconecta del bus. La ECU se
    reengancha sola cada vez, asi que apenas enchufes un nodo el
    contador se queda quieto.

    Si sigue subiendo CON un nodo encendido, entonces el nodo no
    esta llegando al bus: revisar su transceiver, su cableado, y
    que este emitiendo (mirar su puerto serie).

    Si el contador esta en cero y aun asi no se reciben tramas,
    el problema no es el bus sino los identificadores.

La pagina cuenta tramas pero los canales dicen "sin datos"
    El bus anda pero la ECU no reconoce el identificador. Es lo
    que separa "el bus esta mudo" de "el bus habla y no lo
    entiendo": comparar el ID que emite el nodo contra el que
    espera can_ids.h.

El valor del sensor esta multiplicado o dividido por diez
    Emisor y receptor no coinciden en la escala. Estan definidas
    en can_ids.h y las aplican can.cpp de la ECU y el archivo
    sensor_*.cpp del nodo. Los tres tienen que decir lo mismo.

Las RPM salen multiplicadas por un numero entero
    El disco tiene mas de una marca. La constante
    PULSES_PER_REVOLUTION de sensor_wheel_speed.cpp esta en 1 y
    tiene que decir cuantas marcas tiene el disco de verdad.

Las RPM saltan a valores altisimos con el disco quieto
    El preset del modulo esta muy sensible y dispara solo, o
    hay luz infrarroja de fondo, por ejemplo sol directo.
    Ajustar el preset mirando el led del modulo.

El DHT11 no devuelve nada
    Es lo mas comun: falta la resistencia de pull-up en el pin
    de datos, o el cable es muy largo. El nodo reintenta cada
    segundo, asi que si aparece intermitente, es eso.

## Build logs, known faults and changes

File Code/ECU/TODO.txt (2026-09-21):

============================================================
 Proyecto : ECU
 Archivo  : TODO.txt
 Equipo   : UTN BA Motorsport Formula student team
 Fecha    : 2/9/2026

 Descripcion:
 ------------------------------------------------------------
 Estado del firmware. Primero las decisiones ya tomadas, con
 el motivo y que habria que revisar antes de llevarlas al auto
 definitivo. Despues, lo que falta de verdad.

 Notas:
 ------------------------------------------------------------
 Nada de lo que esta en la primera parte bloquea la prueba de
 banco: son elecciones hechas, no huecos. Estan anotadas para
 que se puedan revisar a conciencia mas adelante y no para que
 alguien las descubra de casualidad.

 Al cerrar un punto hay que borrarlo del codigo y de aca, para
 que los dos no se desincronicen.

 Como correr la prueba: ver Code/PRUEBA.txt
============================================================

############################################################
 PARTE 1 - DECISIONES TOMADAS, A REVISAR PARA EL AUTO
############################################################

------------------------------------------------------------
 1.1 Bus CAN
------------------------------------------------------------
Velocidad 500 kbps en las tres placas.
    Es el valor tipico en Formula Student y deja margen de
    sobra para el trafico previsto. A revisar recien si el bus
    queda saturado o si el inversor impone otra.

Identificador 0x480 para el nodo de temperatura.
    El DHT11 no es un sensor del auto, asi que tiene ID propio
    en vez de disfrazarse dentro de una trama del vehiculo que
    significa otra cosa. Cuando entre el sensor real, se retira
    del mapa.

El nodo de velocidad de giro NO usa un ID de banco.
    Usa CAN_ID_RPM_FRONT (0x200), el del auto: medir vueltas por
    minuto contando pulsos es exactamente lo que va a hacer el
    sensor definitivo, asi que ese codigo no se tira.

Layout cerrado de la trama 0x480, en can_ids.h.
    Unidad, escala, rango y endianness definidos. La escala de
    0.1 grados por bit da mas resolucion de la que el DHT11
    entrega: es a proposito, para poder cambiarlo por un sensor
    mejor sin tocar el mapa ni la ECU.

Filtro del bus que acepta todo.
    La ECU necesita ver a todos los nodos para saber cuales
    estan presentes, incluso los que todavia no sabe
    interpretar.

------------------------------------------------------------
 1.2 Maquina de estados
------------------------------------------------------------
Los chequeos de nodos de seguridad dan por buena la situacion.
    En el banco no hay inversor ni BMS en el bus. Si exigieran
    su presencia, el auto entraria en FAULT apenas arranca.
    Ver safetyNodesAreHealthy() y safetyNodeHasFailed() en
    state.cpp: estan escritas, documentadas y listas para
    activarse cuando esos nodos existan.

    OJO: safetyNodeHasFailed() devuelve false y las demas
    condiciones devuelven true. No es un descuido ni una
    inconsistencia: es una condicion de falla, y devolver true
    dejaria el auto muerto en el arranque.

Un corte de comunicacion es WARNING, no FAULT.
    Perder un nodo (0x0002, a los 3 s) o todas las ruedas a la
    vez (0x0003, a los 500 ms) no cambia de estado ni corta la
    grabacion: el auto puede estar perfecto y haberse soltado un
    conector un instante. Queda el aviso en el monitor, se cuenta
    la caida en el CSV y cuando todo vuelve el aviso se borra.
    La ECU trabaja con los nodos que aparecieron en la ventana
    de descubrimiento, no con la lista completa del auto.
    Definido en la prueba de banco; pendiente validar en el
    definitivo, sobre todo si el reglamento pide otra cosa para
    la velocidad.

Cada caida de nodo se cuenta y va al CSV.
    sensorsGetDropCount() por nodo; canales caidas_* en el
    registrador, con valor inicial al arrancar la ejecucion y un
    escalon por cada corte.

De FAULT se sale reiniciando el micro, o solo si la causa se fue.
    FAULT queda para fallas de seguridad reales (categoria B,
    hoy sin implementar). Si la causa desaparece
    (faultCauseHasCleared() en state.cpp), la ECU se rearma y
    vuelve a BOOT, con su ventana de descubrimiento, hasta
    CAR_READY esperando el boton. Las fallas cuya causa no se
    puede comprobar siguen enclavadas.

Duracion de la ejecucion: 90 s por defecto, configurable en la web.
    Los 90 s no salen de ningun reglamento. El campo "Duracion"
    de la pagina viaja con la orden de arranque; tope 180 s
    (MAXIMUM_DURATION_SECONDS en logger.cpp, atado al tamano del
    buffer de muestras).

Ventana de descubrimiento de nodos: 2 segundos.
    Alcanza de sobra para que un ESP32-C3 arranque y mande su
    primera trama. En el auto lo va a fijar el nodo mas lento,
    probablemente el BMS. Ver NODE_DISCOVERY_MILLISECONDS.

El boton alcanza como secuencia de Ready To Drive.
    Para el auto el reglamento exige ademas freno accionado y
    tractive system activo, mas el sonido de RTD antes de
    habilitar torque. Ver readyToDriveSequenceIsComplete().

Si falla el bus CAN, la ECU no crea ninguna task y queda en
rojo fijo.
    Sin bus esta ciega: no hay nada util que pueda hacer.

------------------------------------------------------------
 1.3 Wifi y registro
------------------------------------------------------------
El wifi queda encendido tambien en CAR_ON.
    En el auto tiene que apagarse cuando el torque se habilita.
    En esta prueba los datos salen justamente por wifi mientras
    se graba, que ocurre en CAR_ON. Poner en false la constante
    WIFI_STAYS_ON_IN_CAR_ON de state.cpp restablece el
    comportamiento del auto.

    Pendiente aparte, y este si es importante: confirmar que
    dice el reglamento de la edicion vigente sobre transmision
    inalambrica bidireccional en el auto. Varias ediciones
    restringen la que pueda alterar el comportamiento del
    vehiculo, y actualizar el firmware por OTA lo altera.

El monitoreo web dejo de ser de solo lectura.
    Los endpoints /api/rtd y /api/detener arrancan y cortan la
    ejecucion, porque para la prueba no hay boton fisico de RTD.
    Cualquiera que se conecte al punto de acceso llega a ellos
    sin contraseña.

    En el banco es inofensivo: CAR_ON solo arranca el
    registrador. En el auto ese mismo estado habilita torque.

  [ ] ANTES DE MONTAR LA ECU EN EL AUTO: poner en false la
      constante WEB_CONTROL_ENABLED_FOR_BENCH_TEST de
      webmonitor.cpp. Los endpoints pasan a devolver 403 y los
      botones desaparecen de la pagina.
      Es el unico punto de la Parte 1 que es una tarea y no
      solo una decision a revisar.

Ejecucion de 90 segundos, 20000 muestras como maximo, en PSRAM.
    Con los tres nodos del banco son unas 80 muestras por segundo
    (7300 en 90 s). Con 4000 en RAM interna la grabacion se
    cortaba sola a los 49 s; por eso el buffer paso a la PSRAM
    del S3 con 20000. Ver RECORDING_DURATION_MILLISECONDS y
    MAXIMUM_SAMPLE_COUNT en logger.cpp.

Las muestras se guardan como tuplas y no como filas completas.
    Cada nodo emite a su ritmo: el DHT11 una vez por segundo y
    el de rueda veinte. Guardar filas obligaria a inventar
    valores para el canal que no hablo en ese instante.

Contraseña del wifi: 12345678.
    Es la que estaba de antes. Floja, pero la red no expone nada
    que se pueda cambiar. Si algun dia el monitoreo deja de ser
    de solo lectura, esto pasa a ser un problema real.

############################################################
 PARTE 2 - PENDIENTES DE VERDAD
############################################################

------------------------------------------------------------
 2.1 Datos que hay que medir o conseguir
------------------------------------------------------------
  [ ] include/ECU.h y SensorNode.h
      Los pines de CAN, del boton y de los sensores estan
      definidos para el banco. Confirmarlos contra el
      esquematico de la BaseBoard y el cableado real.

  [ ] sensor_wheel_speed.cpp, PULSES_PER_REVOLUTION
      Esta en 1, o sea una marca por vuelta. Poner cuantas
      marcas tiene el disco que se use de verdad, o las RPM
      salen multiplicadas por ese numero. En el auto lo va a
      fijar la cantidad de dientes de la rueda fonica.

  [ ] include/rules.h
      Los cuatro umbrales de APPS estan con el valor historico
      y hay que validarlos, valor y numero de articulo, contra
      el rulebook de la edicion que se corra.
      RULE_BSE_ACTUATED_BAR esta en 0.0 y hay que medirlo en
      banco: depende del sensor de presion que se elija.
      Este archivo hoy no lo usa nadie: es la especificacion
      para cuando existan el APPS y el BSE.

  [ ] Hoja de datos del inversor.
      Impone su propio protocolo CAN. CAN_ID_DRIVER (0x300) es
      un lugar reservado; es probable que haya que reemplazarlo
      por varios identificadores.

  [ ] Tabla de codigos de falla del equipo.
      ERROR_CODE_SAFETY_NODE_MISSING y ERROR_CODE_NODE_LOST
      en state.cpp son provisorios. Con la tabla completa, cada
      nodo perdido deberia tener su propio codigo en vez de
      compartir uno generico. (Hoy el serie imprime cual fue.)

------------------------------------------------------------
 2.2 Layout de tramas todavia abierto
------------------------------------------------------------
Los nodos de banco ya tienen su layout cerrado. Falta el de
las tramas del auto, en can_ids.h:

  [ ] 0x180  APPS, acelerador
  [ ] 0x181  BSE, freno
  [ ] 0x201  RPM ruedas traseras     (mismo layout que 0x200)
  [ ] 0x202  RPM motor / diferencial  (propuesto, sin validar)

0x200, RPM delanteras, ya esta en uso: lo emite el nodo de
velocidad de giro y lo interpreta la ECU. Falta sumarle la
rueda derecha, que hoy va en cero, y su canal en LogChannel.
  [ ] 0x280  Volante
  [ ] 0x300  Driver / inversor
  [ ] 0x380  BMS / bateria
  [ ] 0x400  IMU
  [ ] 0x500  TPMS
  [ ] 0x080  FAULT: sumar el nodo que origina la falla
  [ ] 0x100  Estado ECU: sumar las flags de presencia

Cada uno necesita las cuatro definiciones de siempre: unidad,
escala, rango y endianness.

------------------------------------------------------------
 2.3 Codigo que falta escribir
------------------------------------------------------------
  [ ] Handler de cada trama del auto en can.cpp.
      Hoy solo estan los dos nodos de banco. El resto de los
      identificadores se reconocen como nodo presente pero no
      se interpretan.

  [ ] Mensaje de configuracion de nodos.
      No existe. Los nodos de banco no lo necesitan porque
      arrancan midiendo solos. Cuando exista, CONFIG tiene que
      esperar el acuse de cada nodo antes de pasar a CAR_READY.
      Ver presentNodesAreConfigured() en state.cpp.

  [ ] Habilitacion y corte de torque en el inversor.
      Los lugares ya estan marcados en enterState(), en las
      entradas a CAR_ON y a FAULT.

  [ ] Indicadores que exige el reglamento: RTD, TSAL, IMD.
      Son otro circuito, no el led RGB de debug de la placa.

------------------------------------------------------------
 2.4 Sin verificar en hardware
------------------------------------------------------------
  [ ] La prueba completa nunca se corrio.
      Los tres firmwares compilan y la ECU arranco bien en la
      placa, pero la cadena entera (dos nodos emitiendo, ECU
      grabando, CSV bajado y graficado) no se probo nunca.

  [ ] La importacion del CSV en MoTeC i2.
      El formato es CSV generico. Abre seguro en Excel y en
      Python; si i2 no lo toma directo va a necesitar una
      conversion.

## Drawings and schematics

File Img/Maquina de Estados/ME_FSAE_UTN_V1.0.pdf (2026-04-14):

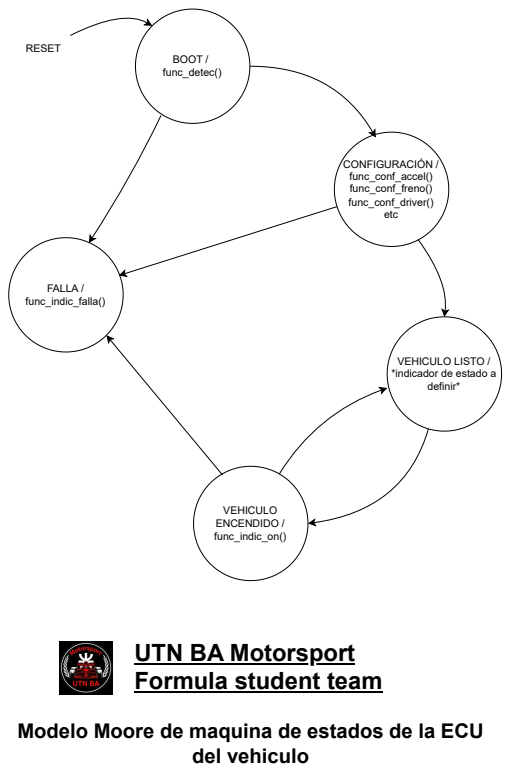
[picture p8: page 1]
BOOT / func_detec(); CONFIGURACIÓN / func_conf_accel() func_conf_freno() func_conf_driver() etc; definir*; VEHICULO ENCENDIDO / func_indic_on(); FALLA / func_indic_falla(); RESET; del vehiculo

VEHICULO LISTO /
*indicador de estado a

UTN BA Motorsport
Formula student team

Modelo Moore de maquina de estados de la ECU

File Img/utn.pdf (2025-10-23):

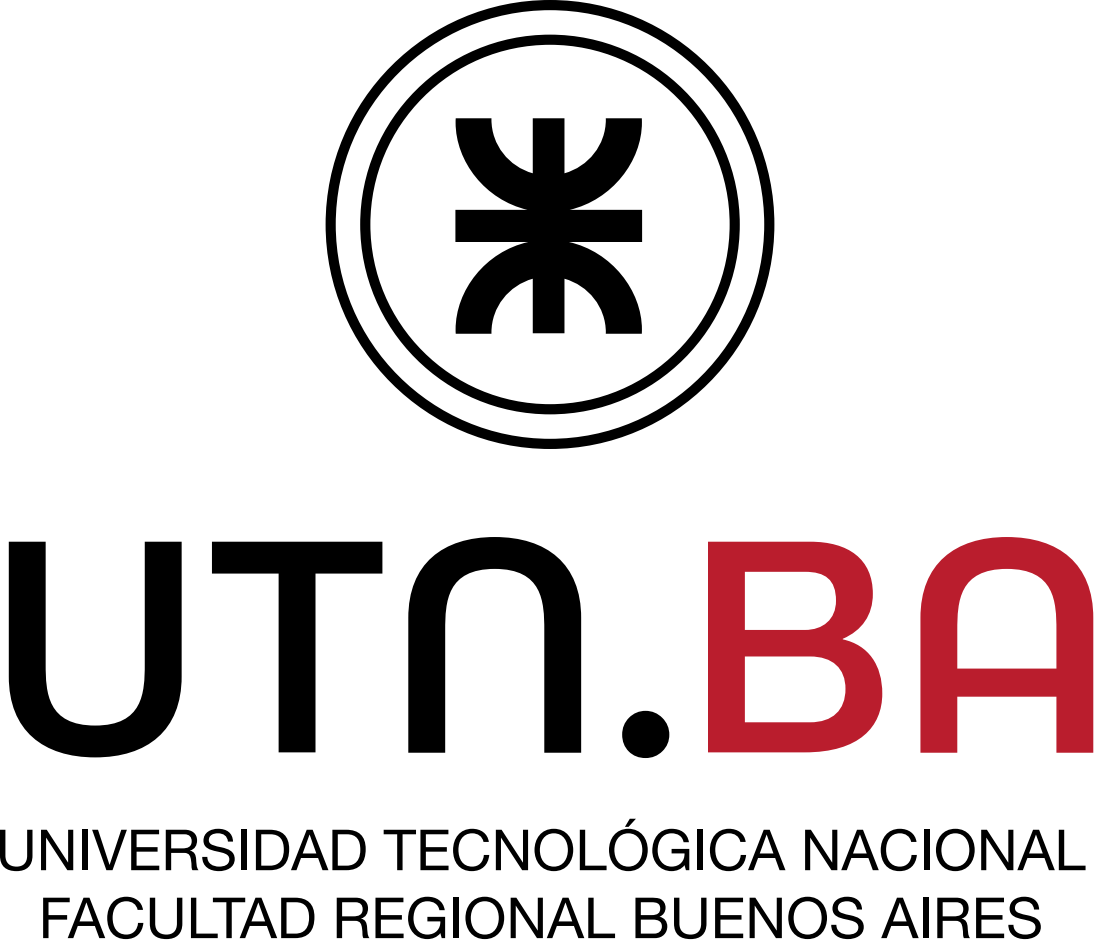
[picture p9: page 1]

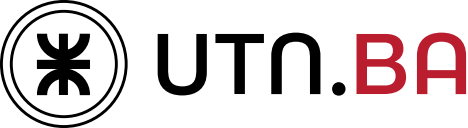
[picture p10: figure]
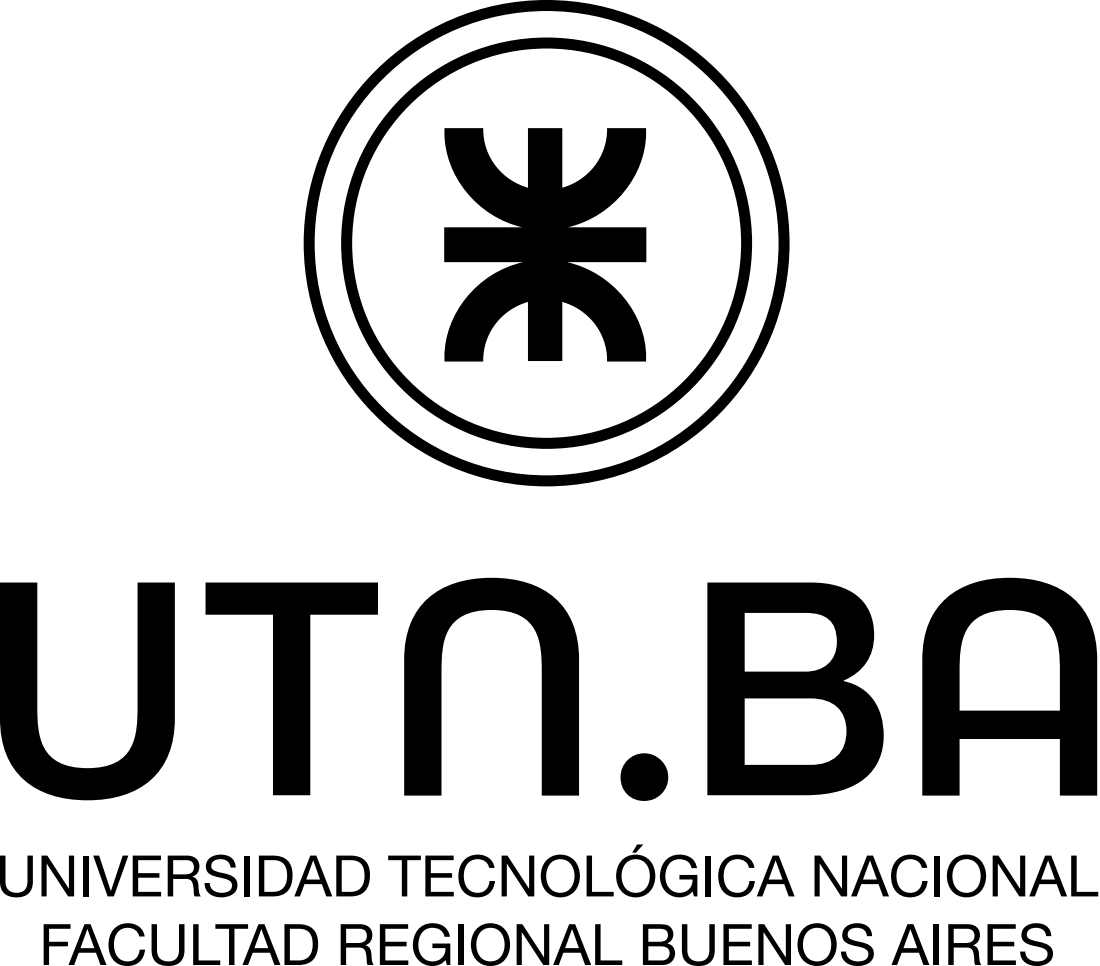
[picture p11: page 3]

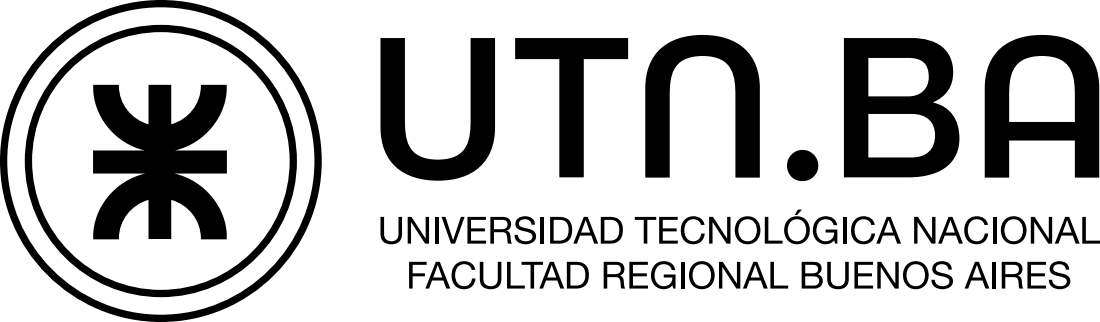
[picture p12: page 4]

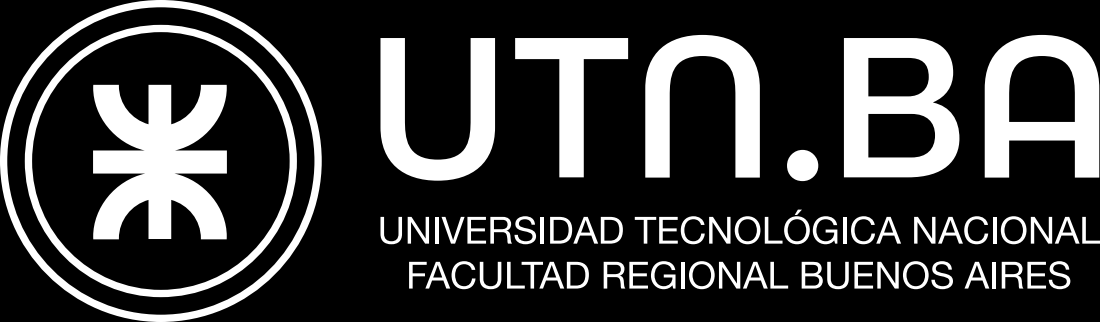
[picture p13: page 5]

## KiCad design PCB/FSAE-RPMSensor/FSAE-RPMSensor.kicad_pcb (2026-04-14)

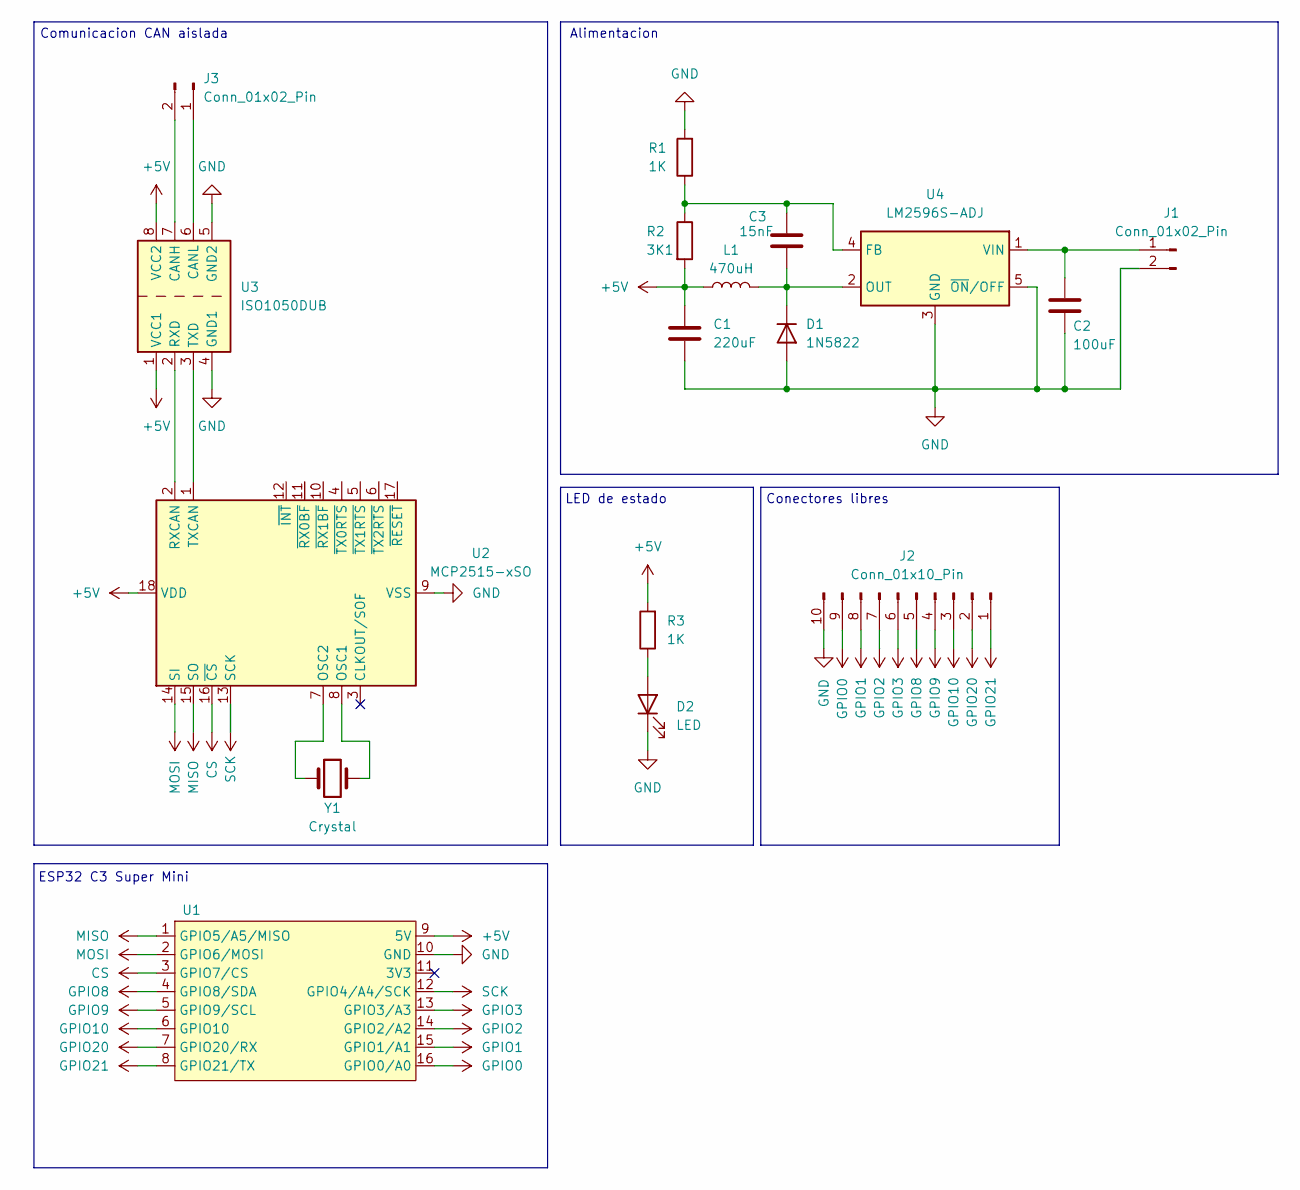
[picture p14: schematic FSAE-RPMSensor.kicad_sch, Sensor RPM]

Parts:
C1: 220uF; C_Elec_8x5.4
C2: 100uF; C_Elec_8x5.4
C3: 15nF; C_0603_1608Metric
D1: 1N5822; D_1206_3216Metric
D2: LED; D_0603_1608Metric
J1, J3: Conn_01x02_Pin; AMASS_XT30U-F_1x02_P5.0mm_Vertical
J2: Conn_01x10_Pin; PinHeader_1x10_P1.00mm_Vertical
L1: 470uH; L_10.4x10.4_H4.8
R1, R3: 1K; R_0603_1608Metric
R2: 3K1; R_0603_1608Metric
U1: ESP32 C3 SM
U2: MCP2515-xSO; SOIC-18W_7.5x11.6mm_P1.27mm
U3: ISO1050DUB; SOP-8_6.62x9.15mm_P2.54mm
U4: LM2596S-ADJ; TO-263-5_TabPin3
Y1: Crystal; Crystal_HC18-U_Vertical

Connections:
+5V: C1.1, L1.1, R2.2, R3.2, U1.9 (5V), U2.18 (VDD), U3.1 (VCC1), U3.8 (VCC2)
CS: U1.3 (GPIO7/CS), U2.16 (~CS)
GND: C1.2, C2.2, D1.2 (A), D2.1 (K), J1.2, J2.10, R1.2, U1.10 (GND), U2.9 (VSS), U3.4 (GND1), U3.5 (GND2), U4.3 (GND), U4.5 (~ON/OFF)
GPIO0: J2.9, U1.16 (GPIO0/A0)
GPIO1: J2.8, U1.15 (GPIO1/A1)
GPIO2: J2.7, U1.14 (GPIO2/A2)
GPIO3: J2.6, U1.13 (GPIO3/A3)
GPIO8: J2.5, U1.4 (GPIO8/SDA)
GPIO9: J2.4, U1.5 (GPIO9/SCL)
GPIO10: J2.3, U1.6 (GPIO10)
GPIO20: J2.2, U1.7 (GPIO20/RX)
GPIO21: J2.1, U1.8 (GPIO21/TX)
MISO: U1.1 (GPIO5/A5/MISO), U2.15 (SO)
MOSI: U1.2 (GPIO6/MOSI), U2.14 (SI)
unnamed: C3.2, D1.1 (K), L1.2, U4.2 (OUT)
unnamed: D2.2 (A), R3.1
unnamed: C2.1, J1.1, U4.1 (VIN)
unnamed: J3.1, U3.6 (CANL)
unnamed: J3.2, U3.7 (CANH)
unnamed: U2.8 (OSC1), Y1.2
unnamed: U2.7 (OSC2), Y1.1
unnamed: U2.2 (RXCAN), U3.2 (RXD)
unnamed: U2.1 (TXCAN), U3.3 (TXD)
unnamed: C3.1, R1.1, R2.1, U4.4 (FB)
SCK: U1.12 (GPIO4/A4/SCK), U2.13 (SCK)

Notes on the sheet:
ESP32 C3 Super Mini
Comunicacion CAN aislada
Conectores libres
LED de estado
Alimentacion

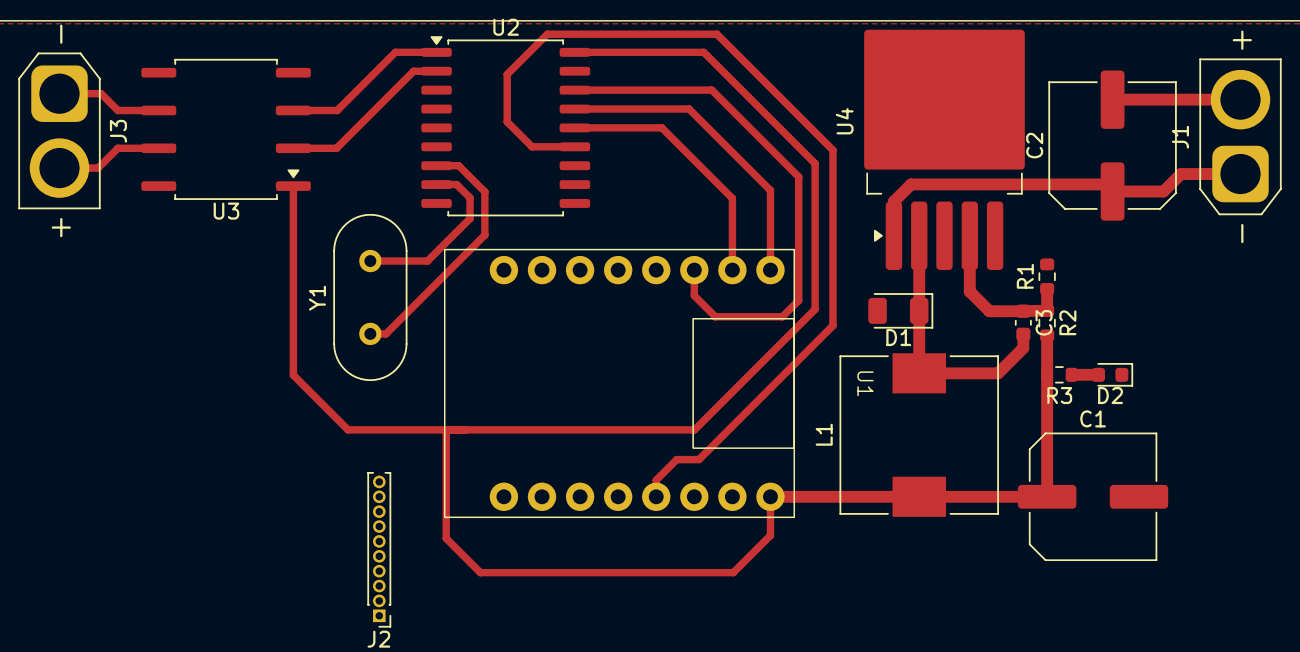
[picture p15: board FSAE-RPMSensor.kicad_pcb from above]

Board: 2 copper layers, 17 parts (0 on the bottom side), 25 nets.

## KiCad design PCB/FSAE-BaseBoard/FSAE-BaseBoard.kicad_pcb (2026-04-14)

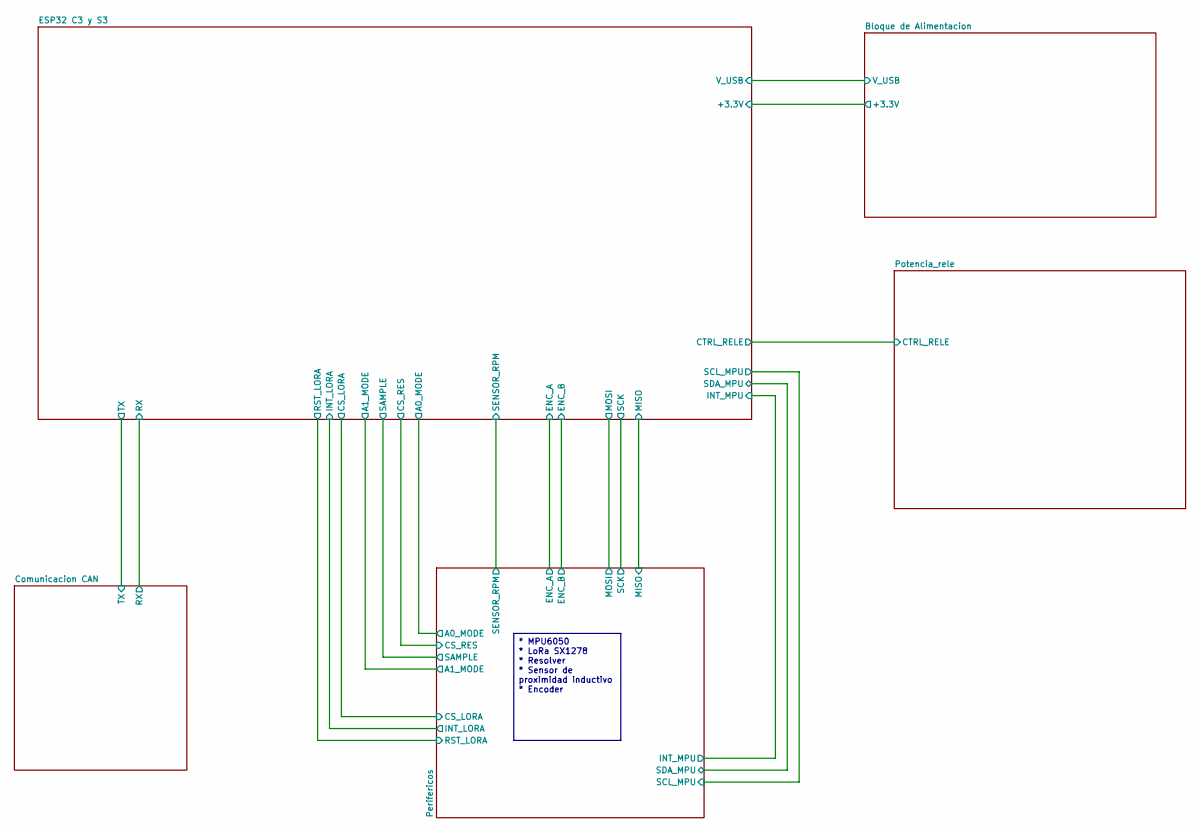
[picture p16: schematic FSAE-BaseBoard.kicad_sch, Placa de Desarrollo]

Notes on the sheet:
* MPU6050 * LoRa SX1278 * Resolver * Sensor de proximidad inductivo * Encoder

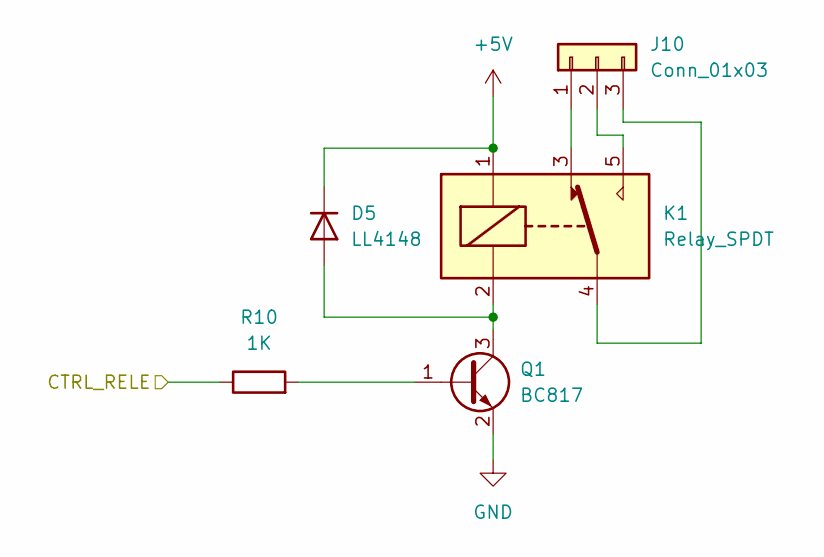
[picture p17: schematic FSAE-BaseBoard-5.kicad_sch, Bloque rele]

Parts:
D5: LL4148; D_MiniMELF
J10: Conn_01x03; PinHeader_1x03_P2.54mm_Vertical
K1: Relay_SPDT; Relay_SPDT_Omron-G5LE-1
Q1: BC817; SOT-23
R10: 1K; R_0805_2012Metric_Pad1.20x1.40mm_HandSolder

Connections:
+5V: D5.1 (K), K1.1; also elsewhere on the board
/ESP32 C3 y S3/CTRL_RELE: R10.1; also elsewhere on the board
GND: Q1.2 (E); also elsewhere on the board
unnamed: D5.2 (A), K1.2, Q1.3 (C)
unnamed: J10.1, K1.3
unnamed: J10.2, K1.5
unnamed: J10.3, K1.4
unnamed: Q1.1 (B), R10.2

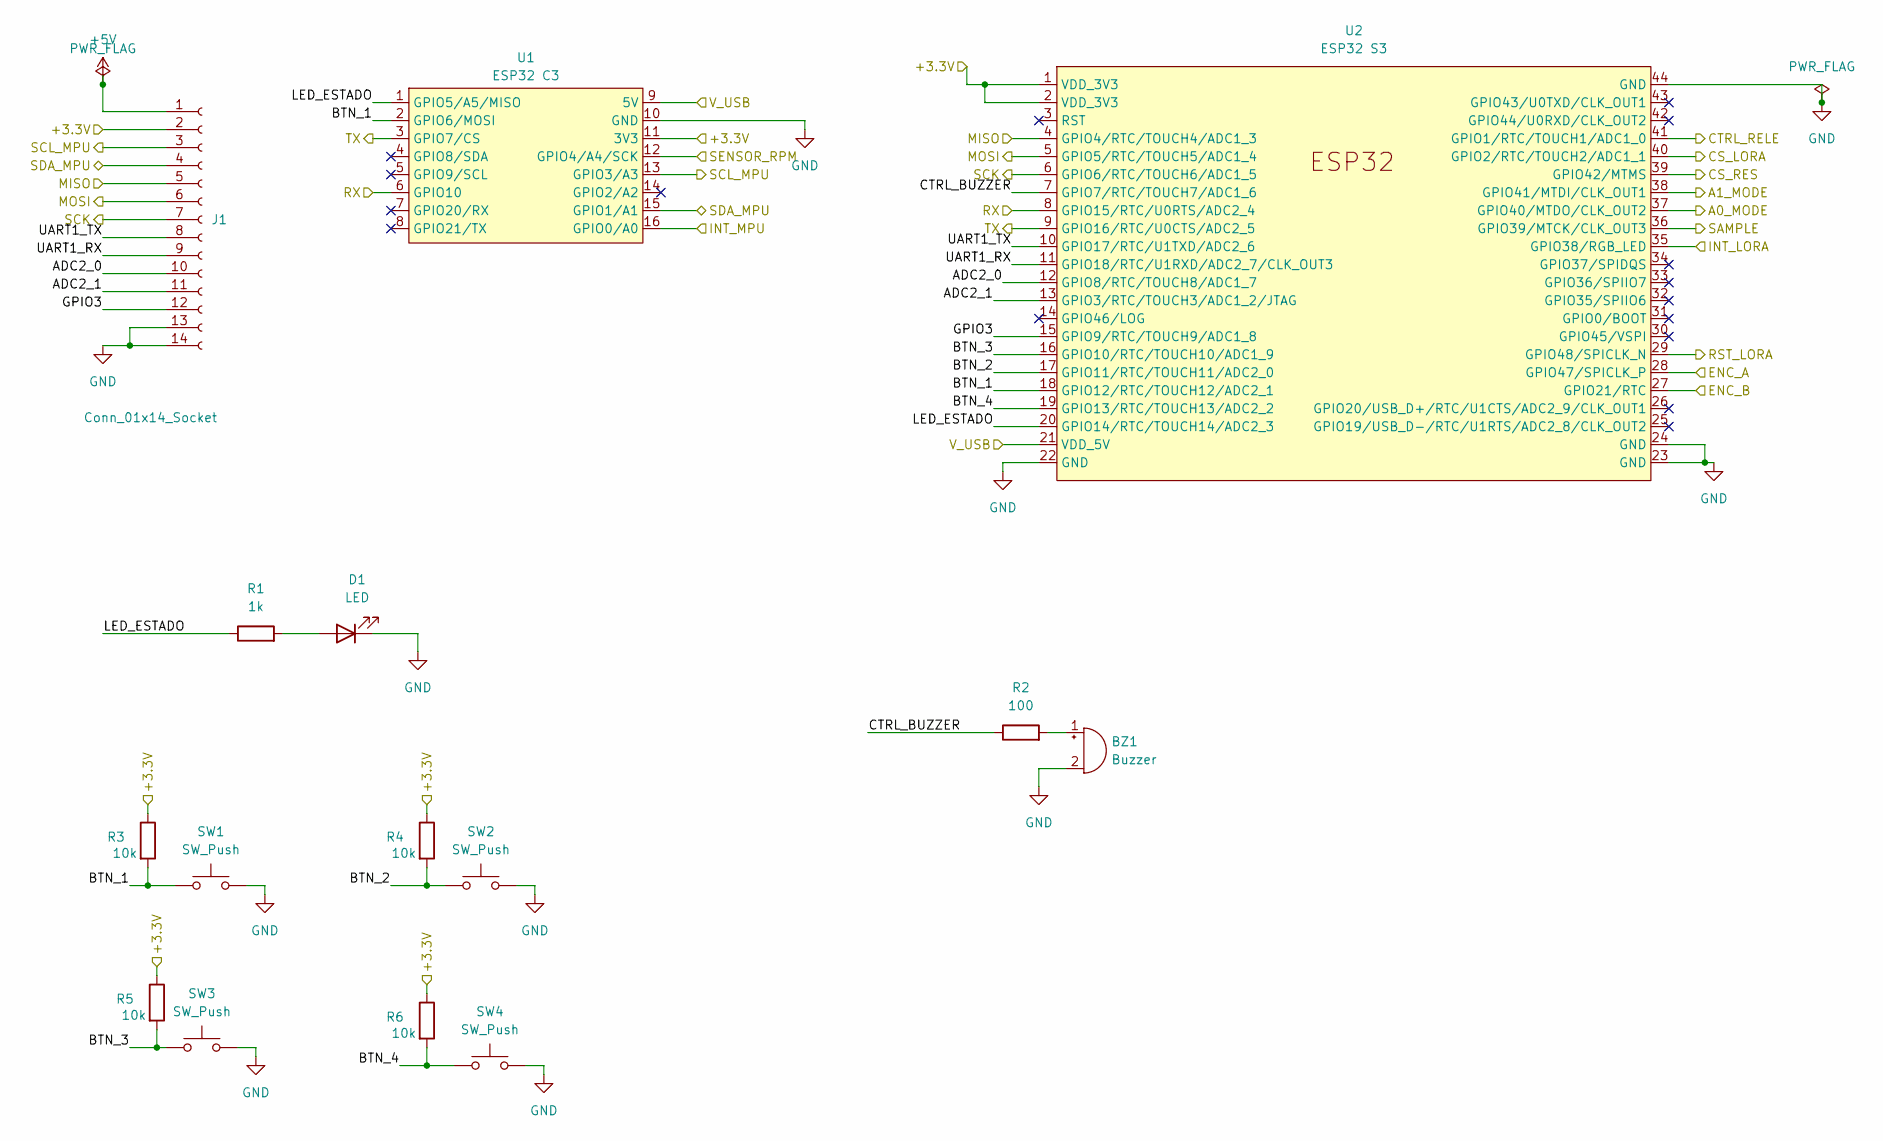
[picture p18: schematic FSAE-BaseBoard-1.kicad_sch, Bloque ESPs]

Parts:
BZ1: Buzzer; Buzzer_12x9.5RM7.6
D1: LED; LED_0805_2012Metric_Pad1.15x1.40mm_HandSolder
J1: Conn_01x14_Socket; PinSocket_1x14_P2.54mm_Vertical
R1: 1k; R_0805_2012Metric_Pad1.20x1.40mm_HandSolder
R2: 100; R_0805_2012Metric_Pad1.20x1.40mm_HandSolder
R3, R4, R5, R6: 10k; R_0805_2012Metric_Pad1.20x1.40mm_HandSolder
SW1, SW2, SW3, SW4: SW_Push; SW_PUSH_6mm_H5mm
U1: ESP32 C3; ESP32 C3 SM
U2: ESP32 S3

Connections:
+3.3V: J1.2, R3.1, R4.1, R5.1, R6.1, U1.11 (3V3), U2.1 (VDD_3V3), U2.2 (VDD_3V3); also elsewhere on the board
+5V: J1.1; also elsewhere on the board
/Bloque de Alimentacion/V_USB: U1.9 (5V), U2.21 (VDD_5V); also elsewhere on the board
/Comunicacion CAN/RX: U1.6 (GPIO10), U2.8 (GPIO15/RTC/U0RTS/ADC2_4); also elsewhere on the board
/Comunicacion CAN/TX: U1.3 (GPIO7/CS), U2.9 (GPIO16/RTC/U0CTS/ADC2_5); also elsewhere on the board
/ESP32 C3 y S3/A0_MODE: U2.37 (GPIO40/MTDO/CLK_OUT2); also elsewhere on the board
/ESP32 C3 y S3/A1_MODE: U2.38 (GPIO41/MTDI/CLK_OUT1); also elsewhere on the board
/ESP32 C3 y S3/ADC2_0: J1.10, U2.12 (GPIO8/RTC/TOUCH8/ADC1_7)
/ESP32 C3 y S3/ADC2_1: J1.11, U2.13 (GPIO3/RTC/TOUCH3/ADC1_2/JTAG)
/ESP32 C3 y S3/BTN_1: R3.2, SW1.1, U1.2 (GPIO6/MOSI), U2.18 (GPIO12/RTC/TOUCH12/ADC2_1)
/ESP32 C3 y S3/BTN_2: R4.2, SW2.1, U2.17 (GPIO11/RTC/TOUCH11/ADC2_0)
/ESP32 C3 y S3/BTN_3: R5.2, SW3.1, U2.16 (GPIO10/RTC/TOUCH10/ADC1_9)
/ESP32 C3 y S3/BTN_4: R6.2, SW4.1, U2.19 (GPIO13/RTC/TOUCH13/ADC2_2)
/ESP32 C3 y S3/CS_LORA: U2.40 (GPIO2/RTC/TOUCH2/ADC1_1); also elsewhere on the board
/ESP32 C3 y S3/CS_RES: U2.39 (GPIO42/MTMS); also elsewhere on the board
/ESP32 C3 y S3/CTRL_BUZZER: R2.1, U2.7 (GPIO7/RTC/TOUCH7/ADC1_6)
/ESP32 C3 y S3/CTRL_RELE: U2.41 (GPIO1/RTC/TOUCH1/ADC1_0); also elsewhere on the board
/ESP32 C3 y S3/ENC_A: U2.28 (GPIO47/SPICLK_P); also elsewhere on the board
/ESP32 C3 y S3/ENC_B: U2.27 (GPIO21/RTC); also elsewhere on the board
/ESP32 C3 y S3/GPIO3: J1.12, U2.15 (GPIO9/RTC/TOUCH9/ADC1_8)
/ESP32 C3 y S3/INT_LORA: U2.35 (GPIO38/RGB_LED); also elsewhere on the board
/ESP32 C3 y S3/INT_MPU: U1.16 (GPIO0/A0); also elsewhere on the board
/ESP32 C3 y S3/LED_ESTADO: R1.1, U1.1 (GPIO5/A5/MISO), U2.20 (GPIO14/RTC/TOUCH14/ADC2_3)
/ESP32 C3 y S3/MISO: J1.5, U2.4 (GPIO4/RTC/TOUCH4/ADC1_3); also elsewhere on the board
/ESP32 C3 y S3/MOSI: J1.6, U2.5 (GPIO5/RTC/TOUCH5/ADC1_4); also elsewhere on the board
/ESP32 C3 y S3/RST_LORA: U2.29 (GPIO48/SPICLK_N); also elsewhere on the board
/ESP32 C3 y S3/SAMPLE: U2.36 (GPIO39/MTCK/CLK_OUT3); also elsewhere on the board
/ESP32 C3 y S3/SCK: J1.7, U2.6 (GPIO6/RTC/TOUCH6/ADC1_5); also elsewhere on the board
/ESP32 C3 y S3/SCL_MPU: J1.3, U1.13 (GPIO3/A3); also elsewhere on the board
/ESP32 C3 y S3/SDA_MPU: J1.4, U1.15 (GPIO1/A1); also elsewhere on the board
/ESP32 C3 y S3/SENSOR_RPM: U1.12 (GPIO4/A4/SCK); also elsewhere on the board
/ESP32 C3 y S3/UART1_RX: J1.9, U2.11 (GPIO18/RTC/U1RXD/ADC2_7/CLK_OUT3)
/ESP32 C3 y S3/UART1_TX: J1.8, U2.10 (GPIO17/RTC/U1TXD/ADC2_6)
GND: BZ1.2 (-), D1.1 (K), J1.13, J1.14, SW1.2, SW2.2, SW3.2, SW4.2, U1.10 (GND), U2.22 (GND), U2.23 (GND), U2.24 (GND), U2.44 (GND); also elsewhere on the board
unnamed: BZ1.1 (+), R2.2
unnamed: D1.2 (A), R1.2

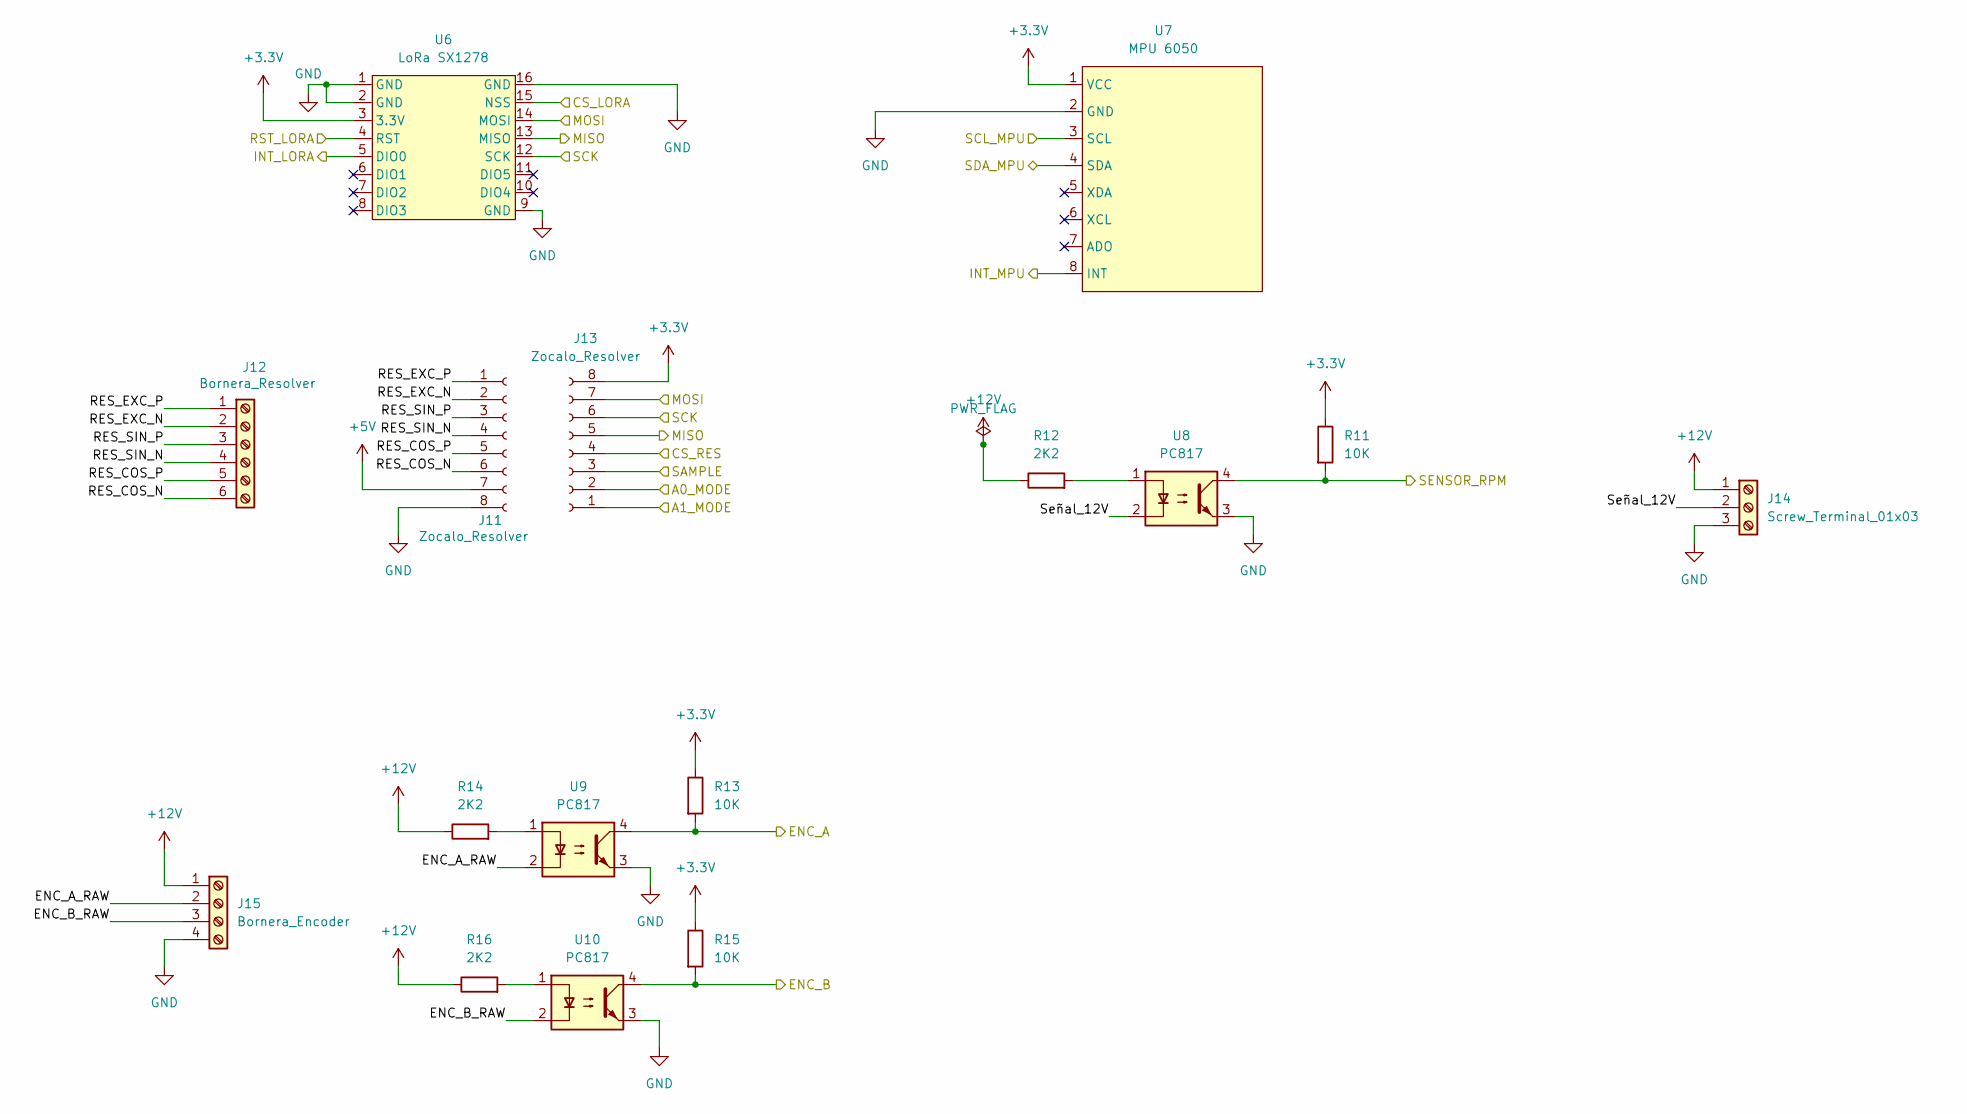
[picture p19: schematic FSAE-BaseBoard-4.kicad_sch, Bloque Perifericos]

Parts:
J11, J13: Zocalo_Resolver; PinSocket_1x08_P2.54mm_Vertical
J12: Bornera_Resolver; TerminalBlock_Phoenix_PT-1,5-6-3.5-H_1x06_P3.50mm_Horizontal
J14: Screw_Terminal_01x03; TerminalBlock_Phoenix_PT-1,5-3-3.5-H_1x03_P3.50mm_Horizontal
J15: Bornera_Encoder; TerminalBlock_Phoenix_PT-1,5-4-3.5-H_1x04_P3.50mm_Horizontal
R11, R13, R15: 10K; R_0805_2012Metric_Pad1.20x1.40mm_HandSolder
R12, R14, R16: 2K2; R_0805_2012Metric_Pad1.20x1.40mm_HandSolder
U6: LoRa SX1278; LoRa_SX178
U7: MPU 6050; MPU6050
U8, U9, U10: PC817; DIP-4_W7.62mm

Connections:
+3.3V: J13.8, R11.1, R13.1, R15.1, U6.3 (3.3V), U7.1 (VCC); also elsewhere on the board
+5V: J11.7; also elsewhere on the board
+12V: J14.1, J15.1, R12.1, R14.1, R16.1
/ESP32 C3 y S3/A0_MODE: J13.2; also elsewhere on the board
/ESP32 C3 y S3/A1_MODE: J13.1; also elsewhere on the board
/ESP32 C3 y S3/CS_LORA: U6.15 (NSS); also elsewhere on the board
/ESP32 C3 y S3/CS_RES: J13.4; also elsewhere on the board
/ESP32 C3 y S3/ENC_A: R13.2, U9.4; also elsewhere on the board
/ESP32 C3 y S3/ENC_B: R15.2, U10.4; also elsewhere on the board
/ESP32 C3 y S3/INT_LORA: U6.5 (DIO0); also elsewhere on the board
/ESP32 C3 y S3/INT_MPU: U7.8 (INT); also elsewhere on the board
/ESP32 C3 y S3/MISO: J13.5, U6.13 (MISO); also elsewhere on the board
/ESP32 C3 y S3/MOSI: J13.7, U6.14 (MOSI); also elsewhere on the board
/ESP32 C3 y S3/RST_LORA: U6.4 (RST); also elsewhere on the board
/ESP32 C3 y S3/SAMPLE: J13.3; also elsewhere on the board
/ESP32 C3 y S3/SCK: J13.6, U6.12 (SCK); also elsewhere on the board
/ESP32 C3 y S3/SCL_MPU: U7.3 (SCL); also elsewhere on the board
/ESP32 C3 y S3/SDA_MPU: U7.4 (SDA); also elsewhere on the board
/ESP32 C3 y S3/SENSOR_RPM: R11.2, U8.4; also elsewhere on the board
/Perifericos/ENC_A_RAW: J15.2, U9.2
/Perifericos/ENC_B_RAW: J15.3, U10.2
/Perifericos/RES_COS_N: J11.6, J12.6
/Perifericos/RES_COS_P: J11.5, J12.5
/Perifericos/RES_EXC_N: J11.2, J12.2
/Perifericos/RES_EXC_P: J11.1, J12.1
/Perifericos/RES_SIN_N: J11.4, J12.4
/Perifericos/RES_SIN_P: J11.3, J12.3
/Perifericos/Señal_12V: J14.2, U8.2
GND: J11.8, J14.3, J15.4, U6.1 (GND), U6.2 (GND), U6.9 (GND), U6.16 (GND), U7.2 (GND), U8.3, U9.3, U10.3; also elsewhere on the board
unnamed: R12.2, U8.1
unnamed: R14.2, U9.1
unnamed: R16.2, U10.1

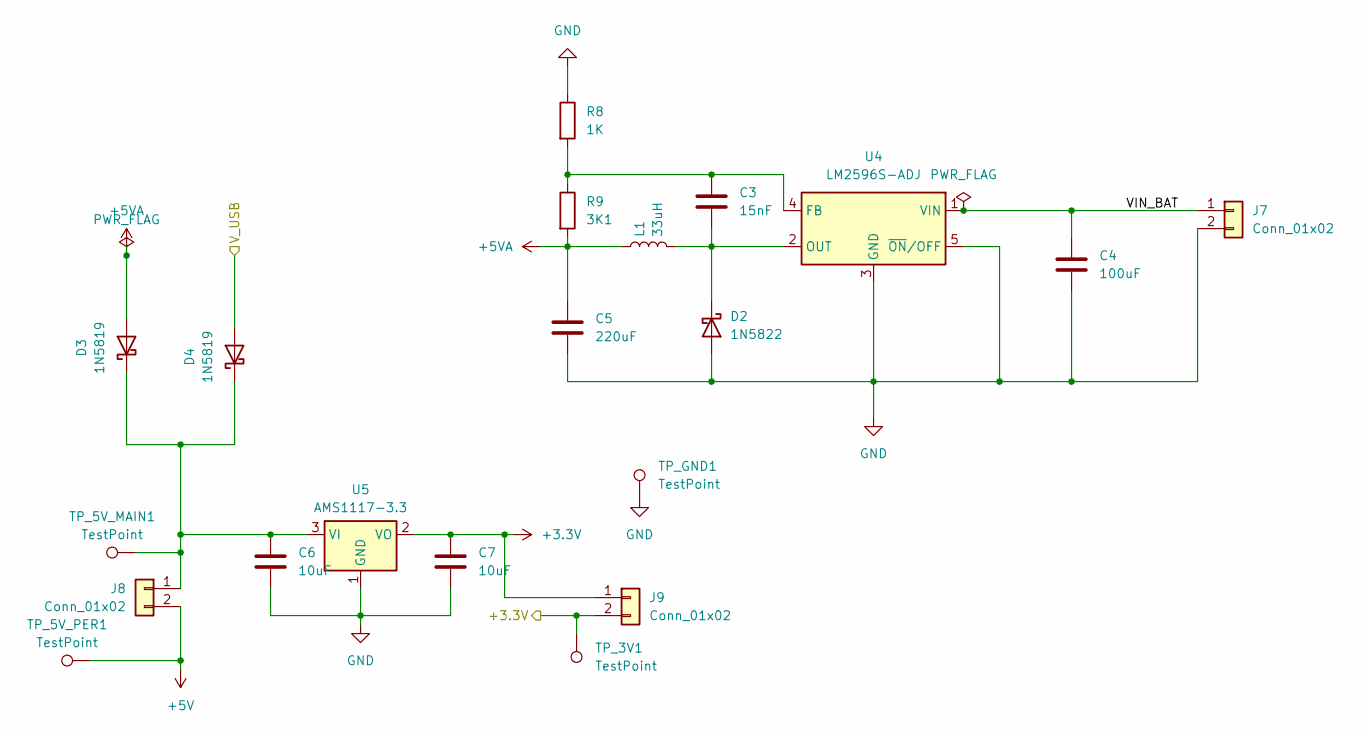
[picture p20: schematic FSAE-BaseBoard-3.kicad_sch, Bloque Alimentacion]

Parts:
C3: 15nF; C_0805_2012Metric_Pad1.18x1.45mm_HandSolder
C4: 100uF; C_0805_2012Metric_Pad1.18x1.45mm_HandSolder
C5: 220uF; C_0805_2012Metric_Pad1.18x1.45mm_HandSolder
C6, C7: 10uF; C_0805_2012Metric_Pad1.18x1.45mm_HandSolder
D2: 1N5822; D_DO-201AD_P15.24mm_Horizontal
D3, D4: 1N5819; D_DO-41_SOD81_P10.16mm_Horizontal
J7, J8, J9: Conn_01x02; PinHeader_1x02_P2.54mm_Vertical
L1: 33uH; L_Wuerth_WE-PD-Typ-LS_Handsoldering
R8: 1K; R_0805_2012Metric_Pad1.20x1.40mm_HandSolder
R9: 3K1; R_0805_2012Metric_Pad1.20x1.40mm_HandSolder
TP_3V1, TP_5V_MAIN1, TP_5V_PER1: TestPoint; TestPoint_THTPad_D2.0mm_Drill1.0mm
TP_GND1: TestPoint; TestPoint_THTPad_2.0x2.0mm_Drill1.0mm
U4: LM2596S-ADJ; TO-263-5_TabPin3
U5: AMS1117-3.3; SOT-223-3_TabPin2

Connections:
+3.3V: C7.1, J9.1, J9.2, TP_3V1.1, U5.2 (VO); also elsewhere on the board
+5V: J8.2, TP_5V_PER1.1; also elsewhere on the board
+5VA: C5.1, D3.2 (A), L1.1, R9.2
/Bloque de Alimentacion/VIN_BAT: C4.1, J7.1, U4.1 (VIN)
/Bloque de Alimentacion/V_USB: D4.2 (A); also elsewhere on the board
GND: C4.2, C5.2, C6.2, C7.2, D2.2 (A), J7.2, R8.1, TP_GND1.1, U4.3 (GND), U4.5 (~ON/OFF), U5.1 (GND); also elsewhere on the board
unnamed: C3.2, D2.1 (K), L1.2, U4.2 (OUT)
unnamed: C6.1, D3.1 (K), D4.1 (K), J8.1, TP_5V_MAIN1.1, U5.3 (VI)
unnamed: C3.1, R8.2, R9.1, U4.4 (FB)

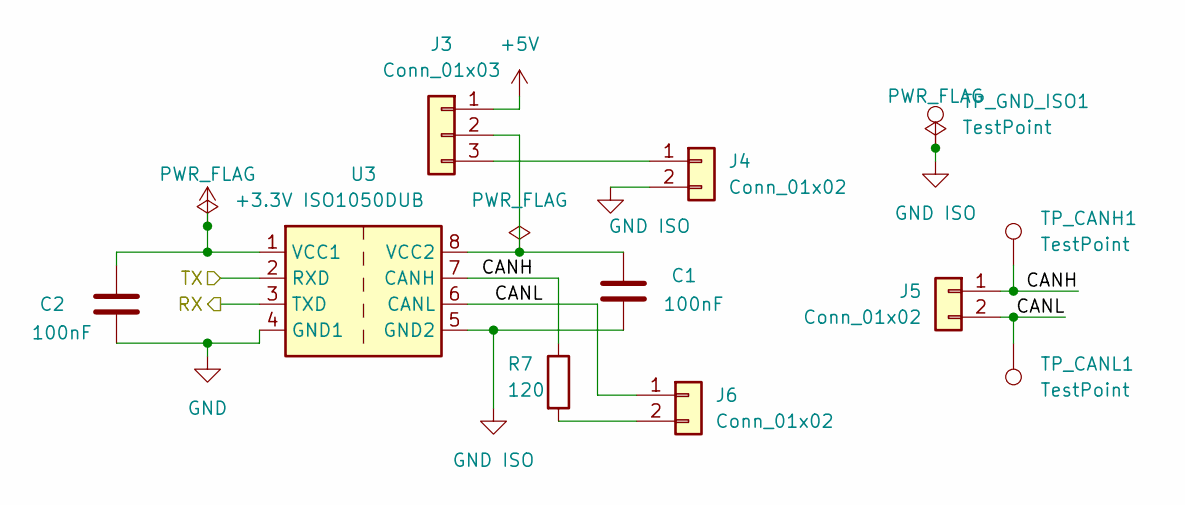
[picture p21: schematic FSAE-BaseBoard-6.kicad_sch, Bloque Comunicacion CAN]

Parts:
C1, C2: 100nF; C_0805_2012Metric_Pad1.18x1.45mm_HandSolder
J3: Conn_01x03; PinHeader_1x03_P2.54mm_Vertical
J4, J5, J6: Conn_01x02; PinHeader_1x02_P2.54mm_Vertical
R7: 120; R_0805_2012Metric_Pad1.20x1.40mm_HandSolder
TP_CANH1: TestPoint; TestPoint_THTPad_D2.0mm_Drill1.0mm
TP_CANL1: TestPoint; TestPoint_THTPad_D2.0mm_Drill1.0mm
TP_GND_ISO1: TestPoint; TestPoint_THTPad_2.0x2.0mm_Drill1.0mm
U3: ISO1050DUB; SOP-8_6.62x9.15mm_P2.54mm

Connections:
+3.3V: C2.1, U3.1 (VCC1); also elsewhere on the board
+5V: J3.1; also elsewhere on the board
/Comunicacion CAN/CANH: J5.1, R7.1, TP_CANH1.1, U3.7 (CANH)
/Comunicacion CAN/CANL: J5.2, J6.1, TP_CANL1.1, U3.6 (CANL)
/Comunicacion CAN/RX: U3.3 (TXD); also elsewhere on the board
/Comunicacion CAN/TX: U3.2 (RXD); also elsewhere on the board
GND: C2.2, U3.4 (GND1); also elsewhere on the board
GND ISO: C1.2, J4.2, TP_GND_ISO1.1, U3.5 (GND2)
unnamed: C1.1, J3.2, U3.8 (VCC2)
unnamed: J3.3, J4.1
unnamed: J6.2, R7.2

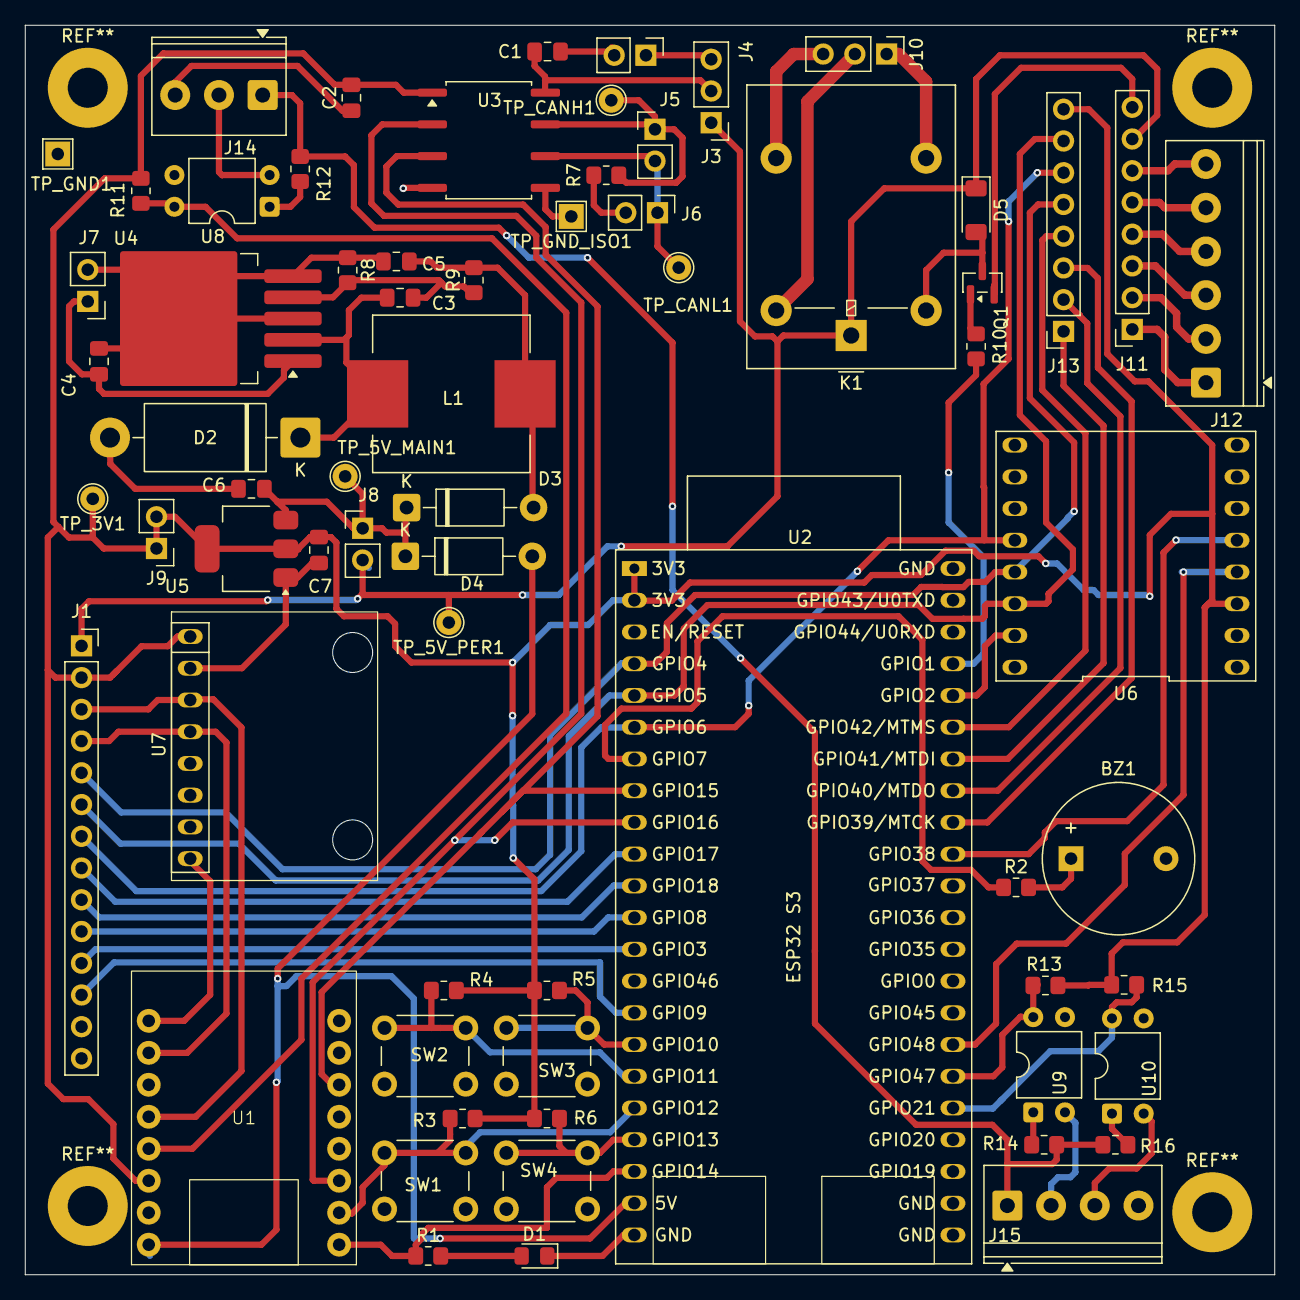
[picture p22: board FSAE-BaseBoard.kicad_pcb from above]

Board: 2 copper layers, 100.0 x 100.0 mm, 67 parts (0 on the bottom side), 65 nets.

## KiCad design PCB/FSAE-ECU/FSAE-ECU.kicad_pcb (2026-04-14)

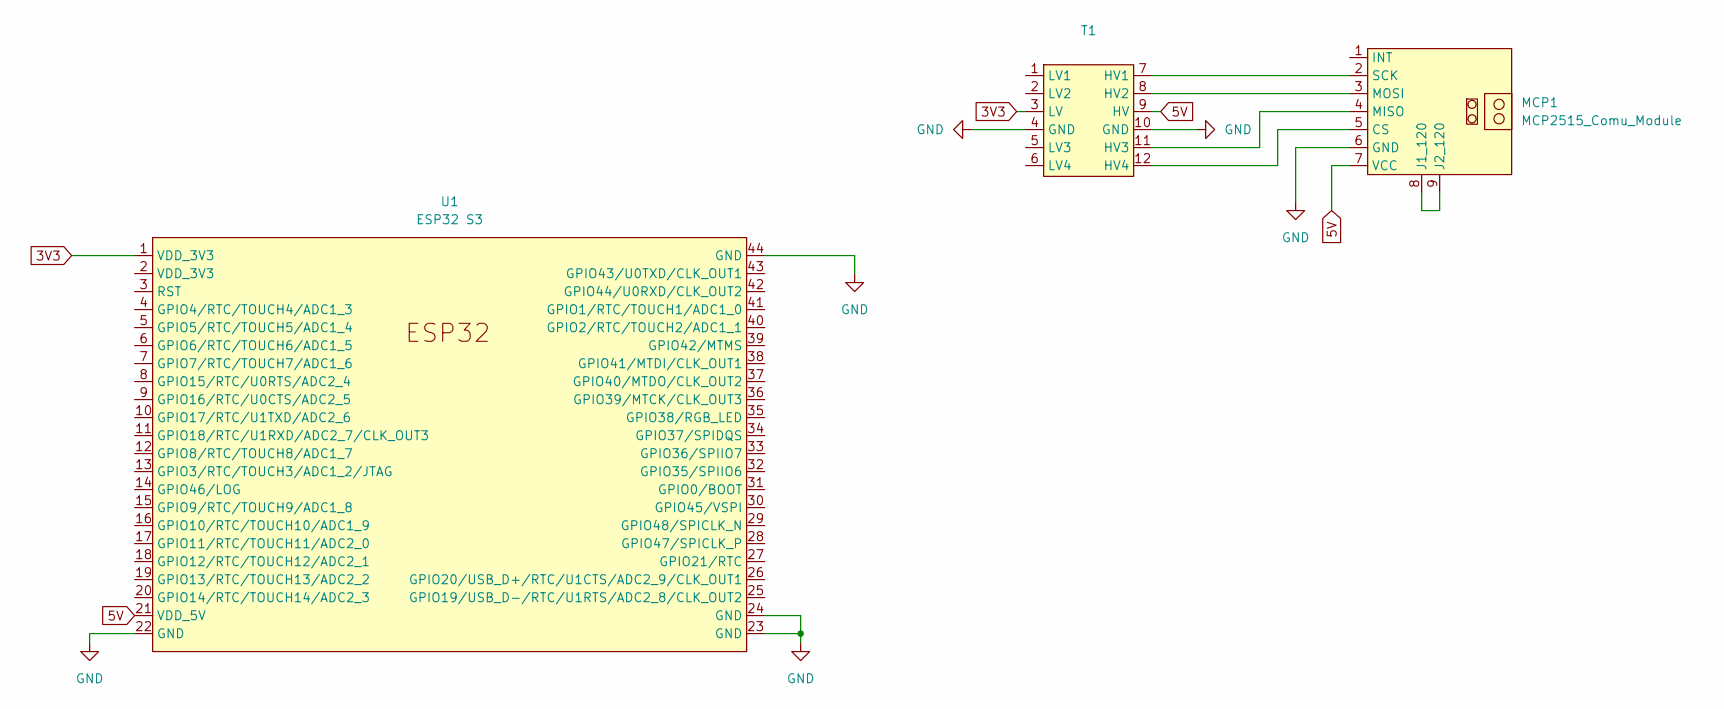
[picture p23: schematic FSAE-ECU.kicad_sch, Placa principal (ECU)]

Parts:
MCP1: MCP2515_Comu_Module; MCP2515_Comun_Module
T1: Conver_Logico
U1: ESP32 S3

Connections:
3V3: T1.3 (LV), U1.1 (VDD_3V3)
5V: MCP1.7 (VCC), T1.9 (HV), U1.21 (VDD_5V)
GND: MCP1.6 (GND), T1.4 (GND), T1.10 (GND), U1.22 (GND), U1.23 (GND), U1.24 (GND), U1.44 (GND)
unnamed: MCP1.4 (MISO), T1.11 (HV3)
unnamed: MCP1.5 (CS), T1.12 (HV4)
unnamed: MCP1.8 (J1_120), MCP1.9 (J2_120)
unnamed: MCP1.3 (MOSI), T1.8 (HV2)
unnamed: MCP1.2 (SCK), T1.7 (HV1)

Board: 2 copper layers, 3 parts (0 on the bottom side), 8 nets, no tracks yet.

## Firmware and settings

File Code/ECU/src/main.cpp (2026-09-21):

/************************************************************
 *  Proyecto : ECU
 *  Archivo  : main.cpp
 *  Equipo   : UTN BA Motorsport Formula student team
 *  Fecha    : 2/9/2026
 *
 *  Descripción:
 *  --------------------------------------------------------
 *  Computadora central de administracion de telemetria de
 *  multiples sensores y estado del vehiculo.
 *
 *  Hardware:
 *  --------------------------------------------------------
 *  - MCU: ESP32 S3.
 *  - Sensores: ninguno propio. Los nodos ESP32-C3 reportan
 *    por CAN.
 *
 *  Notas:
 *  --------------------------------------------------------
 *  Este archivo solo arma el sistema: inicializa el hardware y
 *  crea las tasks. La logica vive en los demas archivos.
 *
 *  Reparto de nucleos: el 1 corre lo que tiene que ser
 *  predecible, estados y CAN; el 0 queda para el wifi, que es
 *  donde el stack de radio ya corre sus propias tasks.
 *
 ************************************************************/

/************************************************************
 *                     INCLUDES
 ************************************************************/
#include "../include/ECU.h"

/************************************************************
 *               CONSTANTES DEL SISTEMA
 ************************************************************/
static const uint16_t STACK_SIZE_STATE = 4096;
static const uint16_t STACK_SIZE_CAN   = 4096;
static const uint16_t STACK_SIZE_WIFI  = 8192; /**< El servidor web necesita mas. */

/* El bus no puede perder tramas esperando a la maquina de estados, por
   eso la task de CAN tiene mas prioridad que la de estados. */
static const uint8_t PRIORITY_CAN   = 4;
static const uint8_t PRIORITY_STATE = 3;
static const uint8_t PRIORITY_WIFI  = 1;

static const uint8_t CORE_REALTIME = 1;
static const uint8_t CORE_WIRELESS = 0;

static const uint8_t QUEUE_LENGTH_EVENTS = 16;
static const uint8_t QUEUE_LENGTH_WIFI   = 4;

/************************************************************
 *                VARIABLES GLOBALES
 ************************************************************/
Adafruit_NeoPixel rgbLed(RGB_LED_COUNT, RGB_LED_PIN, NEO_GRB + NEO_KHZ800);

QueueHandle_t queueEvents = nullptr;
QueueHandle_t queueWifi   = nullptr;

/************************************************************
 *                       SETUP
 ************************************************************/
void setup() {
  Serial.begin(115200);
  delay(1000);

  indicatorsInitialize();
  namesInitialize();

  queueEvents = xQueueCreate(QUEUE_LENGTH_EVENTS, sizeof(EcuEvent));
  queueWifi   = xQueueCreate(QUEUE_LENGTH_WIFI, sizeof(WifiCommand));

  /* Sin bus CAN la ECU esta ciega: no hay nada util que hacer, asi que
     se queda en rojo fijo en lugar de arrancar una maquina de estados
     que nunca va a recibir un dato. */
  if (!canInitialize()) {
    Serial.println("Error: no se pudo inicializar el bus CAN");
    indicatorsSetColor(64, 0, 0);
    return;
  }

  xTaskCreatePinnedToCore(taskState, "state", STACK_SIZE_STATE, nullptr,
                          PRIORITY_STATE, nullptr, CORE_REALTIME);
  xTaskCreatePinnedToCore(taskCan, "can", STACK_SIZE_CAN, nullptr,
                          PRIORITY_CAN, nullptr, CORE_REALTIME);
  xTaskCreatePinnedToCore(taskWifi, "wifi", STACK_SIZE_WIFI, nullptr,
                          PRIORITY_WIFI, nullptr, CORE_WIRELESS);
}

/************************************************************
 *                        LOOP
 ************************************************************/
void loop() {
  /* Todo el trabajo vive en las tasks. Se cede el nucleo para no
     gastarle tiempo al planificador sin motivo. */
  vTaskDelay(pdMS_TO_TICKS(1000));
}

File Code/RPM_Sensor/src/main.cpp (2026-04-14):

/************************************************************
 *  Proyecto : RPM_Sensor
 *  Archivo  : main.cpp
 *  Equipo   : UTN BA Motorsport Formula student team 
 *  Fecha    : 8/1/2026
 *
 *  Descripción:
 *  --------------------------------------------------------
 *  Modulo encargado de la lectura y transmision de los
 *  datos de los sensores de RPM de las ruedas
 *
 *  Hardware:
 *  --------------------------------------------------------
 *  - MCU: ESP32 mini.
 *  - Sensores: Sensor de proximidad inductivo
 *
 *  Notas: El Serial.print no funciona en esta placa. Por
 *         eso esta el telnet que actua de equivalente.
 *  --------------------------------------------------------
 *
 ************************************************************/

/************************************************************
 *                     INCLUDES
 ************************************************************/
#include "../include/RPM.h"

/************************************************************
 *               CONSTANTES DEL SISTEMA
 ************************************************************/

/************************************************************
 *                VARIABLES GLOBALES
 ************************************************************/
bool otaRunning = false;

byte data[] = {0xAA, 0x55, 0x01, 0x10, 0xFF, 0x12, 0x34, 0x56};  // Generic CAN data to send
bool flag = true;

MCP_CAN CAN0(CS_PIN);                               // Set CS to pin 10

WiFiServer telnetServer(23);
WiFiClient telnetClient;

/************************************************************
 *                       SETUP
 ************************************************************/
void setup() {

  otaSetup();

  telnetServer.begin();

  // Initialize MCP2515 running at 8MHz with a baudrate of 50kb/s and the masks and filters disabled.
  if(CAN0.begin(MCP_ANY, CAN_50KBPS, MCP_8MHZ) == CAN_OK)
    flag = true;
  else
    flag = false;
  
  // Since we do not set NORMAL mode, we are in loopback mode by default.
  CAN0.setMode(MCP_NORMAL);                           // Change to normal mode to allow messages to be transmitted

  initSensor();
  //pinMode(INT_PIN, INPUT);                            // Configuring pin for /INT input
  pinMode(LED_PIN,OUTPUT);
  digitalWrite(LED_PIN,LOW);

  
}

/************************************************************
 *                        LOOP
 ************************************************************/
void loop() {
  ArduinoOTA.handle();

  // probamos el sensor
  float currentRPM=getRPM();

  unsigned int rpmInt = (unsigned int)currentRPM;

  // Sobrescribe los dos primeros lugares de byte data porque el protocolo CAB Bus
  // solo acepta paquetes de 8 bytes
  data[0] = (byte)((rpmInt >> 8) & 0xFF);
  data[1] = (byte)(rpmInt & 0xFF);

  // send data:  ID = 0x100, Standard CAN Frame, Data length = 8 bytes, 'data' = array of data bytes to send
  byte sndStat = CAN0.sendMsgBuf(0x100, 0, 8, data);
  if(sndStat == CAN_OK){
    flag = true;
  } else {
    flag = false;
  }

  /***************************************************************************************************** */

  if (!otaRunning) {

    if (telnetServer.hasClient()) {
      if (!telnetClient || !telnetClient.connected()) {
        telnetClient = telnetServer.available();
        telnetClient.println("ESP32 RPM Sensor - Telnet conectado");
      } else {
        telnetServer.available().stop(); // solo 1 cliente
      }
    }

    if (telnetClient && telnetClient.connected()) {
      //telnetClient.println("--------------------");
      
      //telnetClient.println(msgString1);
      //telnetClient.println(msgString2);
      //telnetClient.println("Lectura RPM: ");
      //telnetClient.println(currentRPM);
      telnetClient.println(sndStat);
      telnetClient.println(flag ? "TX OK" : "TX FAIL");       //Hay que conectarse por telnet (preferentemente usando el programa Putty en windows)
      //telnetClient.println("--------------------");         //con la ip 192.168.4.1 y el puerto 23
      
      //telnetClient.print("digital read: ");
      //telnetClient.println(digitalRead(INT_PIN));
      //telnetClient.println("--------------------");
      //newCanMsg = false;
    }
  }
  
  digitalWrite(LED_PIN,HIGH);
  delay(500);

  digitalWrite(LED_PIN,LOW);
  delay(500);

  yield();

}

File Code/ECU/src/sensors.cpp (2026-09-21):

/************************************************************
 *  Proyecto : ECU
 *  Archivo  : sensors.cpp
 *  Equipo   : UTN BA Motorsport Formula student team
 *  Fecha    : 2/9/2026
 *
 *  Descripción:
 *  --------------------------------------------------------
 *  Registro de que nodos estan presentes en el bus CAN.
 *
 *  Hardware:
 *  --------------------------------------------------------
 *  - MCU: ESP32 S3.
 *  - Sensores: cada uno vive en su propia placa y reporta por
 *    CAN. Esta ECU no lee ningun sensor de forma directa.
 *
 *  Notas:
 *  --------------------------------------------------------
 *  Un nodo se considera presente apenas emite una trama. No
 *  hace falta que la ECU le pregunte nada: si esta vivo, habla.
 *
 *  La conversion de cuentas a unidades de ingenieria no vive
 *  aca sino en el handler de cada trama, en can.cpp, que es
 *  donde estan los bytes crudos y el layout que los describe.
 *
 ************************************************************/

/************************************************************
 *                     INCLUDES
 ************************************************************/
#include "../include/ECU.h"
#include "../include/can_ids.h"

/************************************************************
 *                VARIABLES GLOBALES
 ************************************************************/
/* La escribe taskCan y la leen taskState y el monitoreo web. Cada bool
   se toca de a uno y solo pasa de false a true, asi que no necesita
   proteccion. */
static SensorFlags flags = {};

/* Ultima vez que se vio cada nodo, para detectar cuando uno se calla.
   Un valor 0 significa que nunca aparecio. Se indexa por posicion en
   NODE_IDENTIFIERS. */
static const uint32_t NODE_IDENTIFIERS[] = {
    CAN_ID_DRIVER,   CAN_ID_BMS,       CAN_ID_APPS, CAN_ID_BSE,
    CAN_ID_RPM_FRONT, CAN_ID_RPM_REAR, CAN_ID_RPM_MOTOR,
    CAN_ID_STEERING, CAN_ID_IMU,       CAN_ID_TPMS,
    CAN_ID_TEST_TEMPERATURE,
};
static const uint8_t NODE_COUNT = sizeof(NODE_IDENTIFIERS) / sizeof(NODE_IDENTIFIERS[0]);

static uint32_t lastSeenMilliseconds[NODE_COUNT] = {};

/* Estado de silencio de cada nodo y cuantas veces se callo. Los cuenta
   sensorsUpdateSilence(); el contador va al CSV y al monitor. */
static bool     isSilent[NODE_COUNT]  = {};
static uint16_t dropCount[NODE_COUNT] = {};

/* Identificadores que llegaron por el bus y no figuran en can_ids.h.
   Se guardan para mostrarlos en la pagina y poder bautizarlos. */
static uint32_t unknownIdentifiers[UNKNOWN_IDENTIFIER_MAXIMUM] = {};
static uint32_t unknownFrameCounts[UNKNOWN_IDENTIFIER_MAXIMUM] = {};
static uint8_t  unknownCount = 0;

static int8_t findNodeIndex(uint32_t identifier);

/**
 * @brief Marca en las flags que nodo emitio una trama.
 *
 * @param[in]  identifier  Identificador CAN de la trama que llego.
 *
 * @return void
 */
void sensorsMarkNodeSeen(uint32_t identifier) {
  int8_t index = findNodeIndex(identifier);
  if (index >= 0) {
    lastSeenMilliseconds[index] = millis();
  } else {
    sensorsNoteUnknownIdentifier(identifier);
  }

  switch (identifier) {
    case CAN_ID_DRIVER:           flags.driver            = true; break;
    case CAN_ID_BMS:              flags.batteryManagement = true; break;
    case CAN_ID_APPS:             flags.accelerator       = true; break;
    case CAN_ID_BSE:              flags.brake             = true; break;
    case CAN_ID_RPM_FRONT:        flags.wheelSpeedFront   = true; break;
    case CAN_ID_RPM_REAR:         flags.wheelSpeedRear    = true; break;
    case CAN_ID_RPM_MOTOR:        flags.motorSpeed        = true; break;
    case CAN_ID_STEERING:         flags.steeringWheel     = true; break;
    case CAN_ID_IMU:              flags.inertialUnit      = true; break;
    case CAN_ID_TPMS:             flags.tirePressure      = true; break;
    case CAN_ID_TEST_TEMPERATURE: flags.testTemperature   = true; break;

    default:
      break;
  }
}

/**
 * @brief Devuelve las flags de presencia acumuladas.
 *
 * @return SensorFlags  Copia de las flags vigentes.
 */
SensorFlags sensorsGetFlags(void) {
  return flags;
}

/**
 * @brief Cuenta cuantos nodos distintos se detectaron en el bus.
 *
 * @return uint8_t  Cantidad de nodos presentes.
 */
uint8_t sensorsCountPresentNodes(void) {
  uint8_t count = 0;

  if (flags.driver)            count++;
  if (flags.batteryManagement) count++;
  if (flags.accelerator)       count++;
  if (flags.brake)             count++;
  if (flags.wheelSpeedFront)   count++;
  if (flags.wheelSpeedRear)    count++;
  if (flags.motorSpeed)        count++;
  if (flags.steeringWheel)     count++;
  if (flags.inertialUnit)      count++;
  if (flags.tirePressure)      count++;
  if (flags.testTemperature)   count++;

  return count;
}

/**
 * @brief Posicion de un identificador en NODE_IDENTIFIERS.
 *
 * @param[in]  identifier  Identificador CAN.
 *
 * @return int8_t  Indice, o -1 si el identificador no es de un nodo.
 */
static int8_t findNodeIndex(uint32_t identifier) {
  for (uint8_t index = 0; index < NODE_COUNT; index++) {
    if (NODE_IDENTIFIERS[index] == identifier) {
      return index;
    }
  }
  return -1;
}

/**
 * @brief Revisa que nodos se callaron y cuenta cada caida.
 *
 * Solo se miran los nodos que se vieron alguna vez: los que nunca
 * estuvieron no cuentan como perdidos. Asi la ECU trabaja con los nodos
 * que existen en el banco y no con la lista completa del auto.
 *
 * @param[in]  silenceTimeoutMilliseconds  Cuanto silencio se tolera.
 *
 * @return uint32_t  Identificador CAN de un nodo que se acaba de callar
 *                   en esta llamada, o 0 si ninguno cayo ahora.
 */
uint32_t sensorsUpdateSilence(uint32_t silenceTimeoutMilliseconds) {
  uint32_t justDropped = 0;

  for (uint8_t index = 0; index < NODE_COUNT; index++) {
    bool everSeen = (lastSeenMilliseconds[index] != 0);
    bool silent   = everSeen &&
        (millis() - lastSeenMilliseconds[index] > silenceTimeoutMilliseconds);

    if (silent && !isSilent[index]) {
      dropCount[index]++;
      justDropped = NODE_IDENTIFIERS[index];
    }
    isSilent[index] = silent;
  }
  return justDropped;
}

/**
 * @brief Devuelve el primer nodo que esta callado en este momento.
 *
 * @return uint32_t  Identificador CAN, o 0 si todos emiten.
 */
uint32_t sensorsGetSilentNode(void) {
  for (uint8_t index = 0; index < NODE_COUNT; index++) {
    if (isSilent[index]) {
      return NODE_IDENTIFIERS[index];
    }
  }
  return 0;
}

/**
 * @brief Cuantas veces se callo un nodo desde que arranco la ECU.
 *
 * @param[in]  identifier  Identificador CAN del nodo.
 *
 * @return uint16_t  Cantidad de caidas.
 */
uint16_t sensorsGetDropCount(uint32_t identifier) {
  int8_t index = findNodeIndex(identifier);
  return (index < 0) ? 0 : dropCount[index];
}

/**
 * @brief Cantidad de nodos del mapa (can_ids.h) que la ECU vigila.
 *
 * @return uint8_t  Cantidad.
 */
uint8_t sensorsGetKnownNodeCount(void) {
  return NODE_COUNT;
}
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

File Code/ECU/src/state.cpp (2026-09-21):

/************************************************************
 *  Proyecto : ECU
 *  Archivo  : state.cpp
 *  Equipo   : UTN BA Motorsport Formula student team
 *  Fecha    : 2/9/2026
 *
 *  Descripción:
 *  --------------------------------------------------------
 *  Maquina de estados del vehiculo. Unico lugar donde se
 *  decide en que estado esta el auto.
 *
 *  Hardware:
 *  --------------------------------------------------------
 *  - MCU: ESP32 S3.
 *  - Sensores: boton de Ready To Drive en un pin.
 *
 *  Notas:
 *  --------------------------------------------------------
 *  Tabla de transiciones:
 *
 *    BOOT       -> CONFIG      chequeos categoria B en orden
 *    BOOT       -> FAULT       falla categoria B
 *    CONFIG     -> CAR_READY   nodos presentes configurados
 *    CAR_READY  -> CAR_ON      secuencia RTD completa
 *    CAR_ON     -> CAR_READY   apagado pedido, o ejecucion terminada
 *    cualquiera -> FAULT       falla CRITICAL (categoria B)
 *    FAULT      -> BOOT        la causa de la falla desaparecio
 *
 *  Perder nodos o todas las ruedas es WARNING: no cambia el
 *  estado ni corta la grabacion. Ver updateWarnings().
 *
 *  Categoria A, informativo: si el nodo no responde se marca la
 *  flag, se saltea su configuracion, se registra WARNING y se
 *  sigue. Categoria B, seguridad: si no responde o manda valores
 *  implausibles se pasa a FAULT y se corta el torque.
 *
 *  En la prueba de banco no hay ningun nodo de categoria B en el
 *  bus, asi que esos chequeos estan escritos pero dan por buena
 *  la situacion. Queda pendiente activarlos cuando existan el
 *  inversor y el BMS.
 *
 ************************************************************/

/************************************************************
 *                     INCLUDES
 ************************************************************/
#include "../include/ECU.h"
#include "../include/can_ids.h"

/************************************************************
 *               CONSTANTES DEL SISTEMA
 ************************************************************/
static const uint32_t STATE_PERIOD_MILLISECONDS = 10;

/**
 * Tiempo que BOOT espera a que los nodos se presenten en el bus.
 *
 * Definido en 2 segundos para la prueba: alcanza de sobra para que un
 * ESP32-C3 arranque y mande su primera trama. Pendiente medirlo con el
 * auto armado, porque lo va a fijar el nodo mas lento, probablemente
 * el BMS.
 */
static const uint32_t NODE_DISCOVERY_MILLISECONDS = 2000;

/**
 * Silencio que se le tolera a un nodo antes de darlo por perdido.
 *
 * 3 s por el nodo mas lento del banco, el de temperatura, que emite una
 * vez por segundo: se le perdonan dos tramas seguidas. En el auto se
 * ajusta al periodo de cada nodo.
 */
static const uint32_t NODE_SILENCE_TIMEOUT_MILLISECONDS = 3000;

/** Tiempo que el boton tiene que quedar quieto para creerle. */
static const uint32_t BUTTON_DEBOUNCE_MILLISECONDS = 50;

/**
 * Wifi encendido tambien en CAR_ON.
 *
 * En el auto definitivo el wifi tiene que apagarse cuando el torque se
 * habilita. Durante esta prueba los datos salen justamente por wifi
 * mientras se graba, que ocurre en CAR_ON, asi que queda encendido.
 * Poner esto en false restablece el comportamiento del auto.
 */
static const bool WIFI_STAYS_ON_IN_CAR_ON = true;

/*
 * Codigos de falla. Definidos para la prueba; pendiente unificarlos en
 * una tabla del equipo cuando se cierre el layout de la trama 0x080.
 */
static const uint16_t ERROR_CODE_SAFETY_NODE_MISSING = 0x0001;
static const uint16_t ERROR_CODE_NODE_LOST = 0x0002;
static const uint16_t ERROR_CODE_ALL_WHEEL_SPEED_LOST = 0x0003;

/************************************************************
 *                VARIABLES GLOBALES
 ************************************************************/
/* volatile: la escribe esta task y la leen taskCan y el monitoreo web. */
static volatile EcuState currentState = EcuState::BOOT;

static bool readyToDriveRequested = false;
static bool shutdownRequested     = false;

/************************************************************
 *             PROTOTIPOS DE FUNCIONES LOCALES
 ************************************************************/
static bool safetyNodesAreHealthy(void);
static bool safetyNodeHasFailed(void);
static bool presentNodesAreConfigured(void);
static bool readyToDriveSequenceIsComplete(void);
static bool shutdownWasRequested(void);
static bool readyToDriveButtonIsPressed(void);
static bool allWheelSpeedSensorsLost(void);
static void updateWarnings(void);
static bool faultCauseHasCleared(void);
static void recordDropCounts(void);
static void enterState(EcuState nextState);
static void processPendingEvents(void);

/**
 * @brief Devuelve el estado actual del vehiculo.
 *
 * @return EcuState  Estado vigente.
 */
EcuState stateGet(void) {
  return currentState;
}

/**
 * @brief Devuelve el nombre imprimible de un estado.
 *
 * @param[in]  state  Estado a nombrar.
 *
 * @return const char*  Nombre en mayusculas, sin espacios.
 */
const char *stateGetName(EcuState state) {
  switch (state) {
    case EcuState::FAULT:     return "FAULT";
    case EcuState::BOOT:      return "BOOT";
    case EcuState::CONFIG:    return "CONFIG";
    case EcuState::CAR_READY: return "CAR_READY";
    case EcuState::CAR_ON:    return "CAR_ON";
  }
  return "DESCONOCIDO";
}
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

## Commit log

2025-12-23 Primer commit incluyendo el pdf y codigo del primer concepto de maquina de estados de la ECU
2025-12-24 Cargo el codigo inicial para comenzar a programar con algunos comentario y emprolijado
2025-12-24 Agregado de comentarios
2025-12-26 Se carga la simulacion en LTSpice del sistema APPS con potenciometros y distintas funciones transferencias y sin cruces entre ambas
2025-12-29 Se agrega proyecto basico para ESP32 C3 super mini, para los sensores de RPM de las ruedas
2026-01-04 Actualizacion de archivos de simulacion
2026-01-08 Emprolije un poco los archivos y acomode un poco el setup del OTA para poder copiar y pegar el cpp y los includes de los .h en los proximos proyectos
    [FSAE-Telemetria.kicad_pcb, FSAE-Telemetria.kicad_sch]
2026-01-08 Agrego una version con el esp32 C3 super mini funcionando con el modulo can haciendo un loopback (no comunica por can solo es una prueba con el integrado del modulo can) y comunicacion por telnet ya 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
2026-01-09 Subo el codigo del ESP32 C3 super mini ya funcionando con el modulo CAN y habiendo comunicado con un arduino nano.
2026-01-17 Agrego la libreria de kicad arreglada con dos proyectos, uno de la ECU y otro del sensor RPM (este ultimo terminado)
    [FSAE-ECU.kicad_pcb, FSAE-ECU.kicad_sch, FSAE-RPMSensor.kicad_pcb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]
2026-02-02 Modificacion de la placa pcb del modelo de comunicacion CAN por uno aisaldo y con fuente buck para el ESP32 C3
    [FSAE-RPMSensor.kicad_pcb, FSAE-RPMSensor.kicad_sch]
2026-02-05 Implementacion del sensor RPM
2026-02-19 Creacion de la placa de desarrollo y actualizalcion del esquematico
    [FSAE-BaseBoard-1.kicad_sch, FSAE-BaseBoard-2.kicad_sch, FSAE-BaseBoard-3.kicad_sch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]
2026-02-19 Eliminar carpeta
    [Primero_esquematico.kicad_pcb, Primero_esquematico.kicad_sch]
2026-03-08 Actualizacion de la placa de desarollo - v.2
    [FSAE-BaseBoard-1.kicad_sch, FSAE-BaseBoard-3.kicad_sch, FSAE-BaseBoard-4.kicad_sch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]
2026-04-12 Actualizacion diseño BaseBoard
    [FSAE-BaseBoard-1.kicad_sch, FSAE-BaseBoard-3.kicad_sch, FSAE-BaseBoard-4.kicad_sch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]
2026-09-02 Restaurar simulaciones LTspice del APPS
    Los cuatro archivos de Sim/ se borraron del disco y el commit e8575db
    se los llevo de arrastre junto con el firmware de la ECU. No fue una
    decision: quedaron pendientes en el working tree y entraron solos.
    Se restauran tal cual estaban en 99ab34a. APPS Transfer Funtions.asc
    es la transferencia del acelerador, que hace falta para el escalado
    en sensorsScaleApps().
2026-09-04 avance ecu para prueba + todo prueba real futura
2026-09-21 Prueba ECU con varios sensores + posibilidad de conexion de nuevos sensores
2026-09-25 psb de baterias a bms V1
    Faltan footprints del conector y el fusible y seleccionar el fusible
2026-10-14 Primer diseño de pcb listo
    Faltan re confirmar si cumple con todas las normativas para ya hacer el primer prototipo
2026-10-16 ECU: pantalla del piloto, lectura del Orion BMS y avisos
    - Pantalla TFT 4" (ST7796S) en un SPI propio: estado, velocidad, barra
    de RPM, acelerador y freno, bateria con cortes en 25/50/75 % y franja
    de avisos. Fuente suavizada propia para el estado.
    - Lectura del estado de carga del Orion BMS 2. Trama, byte, escala y
    velocidad del bus configurables desde la web.
    - Sin bateria informando no se pasa a CAR_READY; si el CAN no arranca,
    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
2026-10-23 ECU: APPS, freno y shutdown; correccion del BMS
    - Lectura directa de APPS (dos potenciometros) y sensor de freno por el
    ADC1, sensores de 5 V por divisor 10 k / 15 k, y del shutdown circuit
    por contacto de rele. Calibracion de reposo y a fondo desde la web.
    - Fallas: shutdown abierto, APPS fuera de banda o en desacuerdo y freno
    fuera de banda llevan a FAULT, del que se sale solo al resolverse.
    Freno y acelerador a la vez es aviso.
    - Alertas: la franja de la pantalla parpadea en rojo con la causa.
    - Chequeos activables desde la web (bateria, shutdown, pedales).
    - BMS: una trama mas corta que el byte configurado ya no cuenta como
    bateria informando (mostraba un valor viejo, el 12 % s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
2026-11-03 Pcb celdas a bms
    Ya esta lilsta la parte de medir tension falta la parte para midir temperatiura
2026-11-06 ECU 1.0 stm32
2026-11-06 Entrega PCB V4
    Agrege vias y doble pista en top y en buttom
2026-11-10 Add files via upload
    Esquemático para el funcionamiento de las luces, incluye las librerías. Los warnings que aparecen provienen de no tener el conector (se soluciona al ponerlo), no altera al resto.
2026-11-12 Add files via upload
    2da versión del esquemático para las luces.
    Correcciones realizadas: Se agregaron los valores de resistencias y capacitores en sus descripciones, la tabla de verdad para el funcionamiento lógico y el gráfico de intersección de las señales del 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
